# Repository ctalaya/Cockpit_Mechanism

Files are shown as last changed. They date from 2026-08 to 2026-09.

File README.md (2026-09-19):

# Cockpit_Mechanism

Modelos CAD y de simulación de un cockpit de simulación de conducción con geometría variable, capaz de reconfigurarse entre una posición de conducción tipo GT y una posición tipo Fórmula.

Este repositorio contiene los archivos que sustentan los resultados del Trabajo Fin de Máster **«Diseño y análisis cinemático de un cockpit de simulación de conducción con geometría variable»**, Máster Universitario en Ingeniería Industrial, Universidad Internacional de Valencia (VIU), curso 2025–2026.

**Autor:** Carlos Talaya Zamora
**Director:** José Andrés Alvarado Contreras

---

## Descripción del mecanismo

El mecanismo posee **dos grados de libertad** (criterio de Grübler-Kutzbach) gobernados por dos entradas de accionamiento coordinadas:

1. **Giro del asiento** sobre un eje fijo situado en el H-Point del conductor. Este giro arrastra, mediante un tren formado por un sector dentado, un piñón, un engranaje intermedio y una cremallera, el desplazamiento del módulo volante-pantalla sobre una guía inclinada.
2. **Actuador lineal** que gobierna el brazo estructural de la pedalera y, a través de una transmisión por cadena, el giro de la propia pedalera respecto a dicho brazo.

El H-Point permanece fijo durante toda la transformación, lo que constituye el criterio de diseño fundamental del mecanismo: el conductor no se desplaza en altura, sino que rota alrededor de su propio punto de cadera.

---

## Especificaciones de diseño

Recorridos requeridos para la transición GT → Fórmula, referidos al H-Point:

| Magnitud | Valor |
|---|---|
| Desplazamiento horizontal del volante | 237,39 mm |
| Desplazamiento vertical del volante | 70,64 mm |
| Desplazamiento longitudinal de la pedalera | 69,90 mm |
| Desplazamiento vertical de la pedalera | 553,65 mm |
| Giro del asiento sobre el H-Point | 32,5° |
| Giro absoluto de la pedalera | 21° |
| Desplazamiento del H-Point | 0 mm (punto fijo) |

## Parámetros de las transmisiones

**Tren de engranajes del módulo volante** (módulo m = 2 mm, ancho de cara 20 mm)

| Elemento | z | R primitivo |
|---|---|---|
| Sector dentado del asiento | 291 | 291,0 mm |
| Piñón | 20 | 20,0 mm |
| Engranaje intermedio | 30 | 30,0 mm |

Relación de transmisión i₁ = 14,555 · Recorrido de la cremallera 247,68 mm · Inclinación de la guía 16,58°

**Transmisión por cadena de la pedalera** (ISO 08B, paso 12,7 mm)

| Elemento | z | R primitivo |
|---|---|---|
| Piñón solidario al asiento | 27 | 54,70 mm |
| Piñón solidario a la pedalera | 15 | 30,55 mm |

Relación de transmisión i₂ = 1,7905 · Distancia entre ejes 387,0 mm · Longitud de cadena 82 eslabones (1.041,4 mm)

**Actuador lineal**

Longitud de referencia 150,0 mm · Carrera 17,86 mm · Giro relativo del brazo β = 14,55° · Velocidad de extensión 0,595 mm/s · Tiempo de operación 30 s

---

## Resultados de validación

Contraste entre los requisitos de diseño y los valores obtenidos en la simulación cinemática:

| Magnitud | Requisito | Simulación | Desviación |
|---|---|---|---|
| Desplazamiento horizontal del volante | 237,39 mm | 237,41 mm | 0,01 % |
| Desplazamiento vertical del volante | 70,64 mm | 70,64 mm | 0,00 % |
| Desplazamiento longitudinal de la pedalera | 69,90 mm | 70,09 mm | 0,27 % |
| Desplazamiento vertical de la pedalera | 553,65 mm | 551,46 mm | −0,40 % |
| Giro del asiento sobre el H-Point | 32,50° | 32,504° | 0,01 % |
| Giro absoluto de la pedalera | 21,00° | 21,04° | 0,19 % |

## Resultados dinámicos

Solicitaciones obtenidas en el análisis dinámico, por lateral del mecanismo:

| Magnitud | t = 0 s (GT) | t = 30 s (Fórmula) |
|---|---|---|
| Reacción en el apoyo del H-Point | 1.007,40 N | 1.007,40 N |
| Guía del módulo volante-pantalla | 305,90 N | 305,90 N |
| Revoluta brazo-pedalera | 249,48 N | 249,47 N |
| Revoluta asiento-brazo | 2.469,40 N | 3.511,60 N |
| Pasadores del actuador | 2.455,20 N | 3.667,40 N |
| Fuerza del actuador lineal | 2.455,70 N | 3.665,70 N |
| Par en el eje del H-Point | 141,93 N·m | 138,45 N·m |

El par alcanza su valor máximo de 151,71 N·m en t = 13,82 s. El mecanismo no presenta un instante crítico común a todas sus piezas: las solicitaciones de origen gravitatorio permanecen constantes, mientras que las asociadas al accionamiento del brazo crecen de forma monótona hasta la configuración Fórmula.

## Verificación resistente de las transmisiones

Acero S275JR, límite elástico 275 MPa.

| Elemento | Tensión | Factor de seguridad |
|---|---|---|
| Sector dentado (Lewis) | 5,69 MPa | 48,3 |
| Piñón (Lewis) | 8,56 MPa | 32,1 |
| Cremallera (Lewis) | 3,80 MPa | 72,5 |
| Cadena ISO 08B-1 (rotura) | T = 775 N | 23,2 |

Ambas transmisiones quedan gobernadas por las exigencias cinemáticas y no por las resistentes, lo que deja un margen de optimización económica pendiente de estudio específico.

---

## Estructura del repositorio

```
Cockpit_Mechanism/
├── Diseño 3D/
│   └── V2/              Modelo tridimensional del mecanismo (CATIA V5)
│       └── Planos/      Planos de conjunto y de detalle
├── Calculo/             Modelos de simulación de Ansys
├── Resultados/          Exportaciones de resultados en formato .xlsx
├── .gitattributes       Configuración de Git LFS
└── README.md
```

### Diseño 3D/V2

Modelo tridimensional completo del mecanismo elaborado en CATIA V5, en sus dos configuraciones extremas. Incluye las cinco piezas estructurales analizadas (eje del H-Point, asiento, brazo estructural de la pedalera, pedalera y soporte del volante-pantalla) y los componentes de las transmisiones.

### Calculo

Modelos de simulación:

- **Ansys Rigid Dynamics** — análisis cinemático y dinámico del mecanismo completo a lo largo de los 30 s de la transformación.
- **Ansys Mechanical** — análisis estructural estático de cada una de las cinco piezas.

### Resultados

Exportaciones de resultados en formato `.xlsx`, con 603 pasos de tiempo cada una:

- `Cinematica.xlsx` — giros, velocidades y aceleraciones angulares de los tres ejes principales.
- `Fuerzas internas.xlsx` — fuerzas transmitidas en las seis uniones del mecanismo.
- `Fuerzas actuador y par.xlsx` — fuerza requerida en el actuador lineal y par en el eje del H-Point.

---

## Nota sobre las Constraint Equations

Los engranajes y la transmisión por cadena se han modelado sin dentado, representándolos por sus cilindros primitivos. Las relaciones de transmisión se imponen mediante **Constraint Equations** sobre los grados de libertad de los joints, procedimiento documentado por Ansys para vincular velocidades angulares sin necesidad de modelar el contacto entre dientes.

Esta simplificación es deliberada: el objetivo del análisis es verificar la cinemática de la transformación, no evaluar tensiones de contacto en el dentado. Como consecuencia, el modelo no proporciona fuerzas de engrane ni presiones de contacto, y la transmisión es ideal, sin holguras ni pérdidas por rozamiento.

Debe señalarse que, al no derivarse estas ecuaciones de la geometría sino imponerse explícitamente, el programa reproduce la relación indicada sea o no la correcta. La verificación independiente de las magnitudes de salida frente a los requisitos de partida resulta, por tanto, imprescindible.

---

## Requisitos de software

| Software | Versión empleada |
|---|---|
| CATIA V5 | — |
| Ansys Mechanical / Rigid Dynamics | 2025 R1 |
| Git LFS | Necesario para clonar el repositorio |

## Clonado del repositorio

Los archivos de modelado y simulación se almacenan mediante **Git Large File Storage**. Es necesario instalar Git LFS antes de clonar:

```bash
git lfs install
git clone https://github.com/ctalaya/Cockpit_Mechanism.git
```

Sin Git LFS, el clonado descargará únicamente los punteros a los archivos, no su contenido.

---

## Licencia y uso

Este repositorio se publica con fines académicos, como material de soporte y verificación del Trabajo Fin de Máster referido. Cualquier uso posterior de su contenido debe citar la fuente:

> Talaya Zamora, C. (2026). *Cockpit_Mechanism: modelos CAD y de simulación de un cockpit reconfigurable* [Repositorio de software]. GitHub. https://github.com/ctalaya/Cockpit_Mechanism

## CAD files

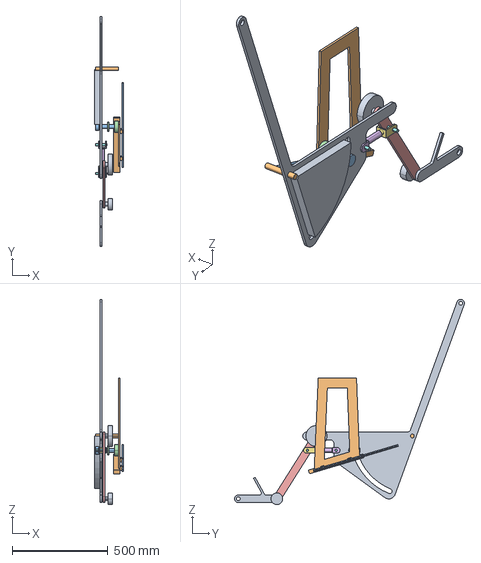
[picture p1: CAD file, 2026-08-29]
Calculo/Modelo/TFM_V2.stp
153.0 x 1199.4 x 1070.5 mm

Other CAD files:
Diseño 3D/V2/Actuador/Actuador.CATProduct
Diseño 3D/V2/Actuador/Base actuador.CATPart
Diseño 3D/V2/Actuador/Vastago actuador.CATPart
Diseño 3D/V2/Asiento V2.CATPart
Diseño 3D/V2/Brazo Estructural de la Pedalera V2.CATPart
Diseño 3D/V2/Brazo exterior volante V2.CATPart
Diseño 3D/V2/Brazo interior volante V2.CATPart
Diseño 3D/V2/Eje V2.CATPart
Diseño 3D/V2/Eje2.CATPart
Diseño 3D/V2/Engranaje Grande.CATPart
Diseño 3D/V2/Engranaje Peque.CATPart
Diseño 3D/V2/Guia V2.CATPart
Diseño 3D/V2/Guia Volante.CATPart
Diseño 3D/V2/Mecanismo Cockpit V2.CATProduct
Diseño 3D/V2/Pedalera V2.CATPart
Diseño 3D/V2/Soporte Eje.CATPart
Diseño 3D/V2/Volante.CATPart

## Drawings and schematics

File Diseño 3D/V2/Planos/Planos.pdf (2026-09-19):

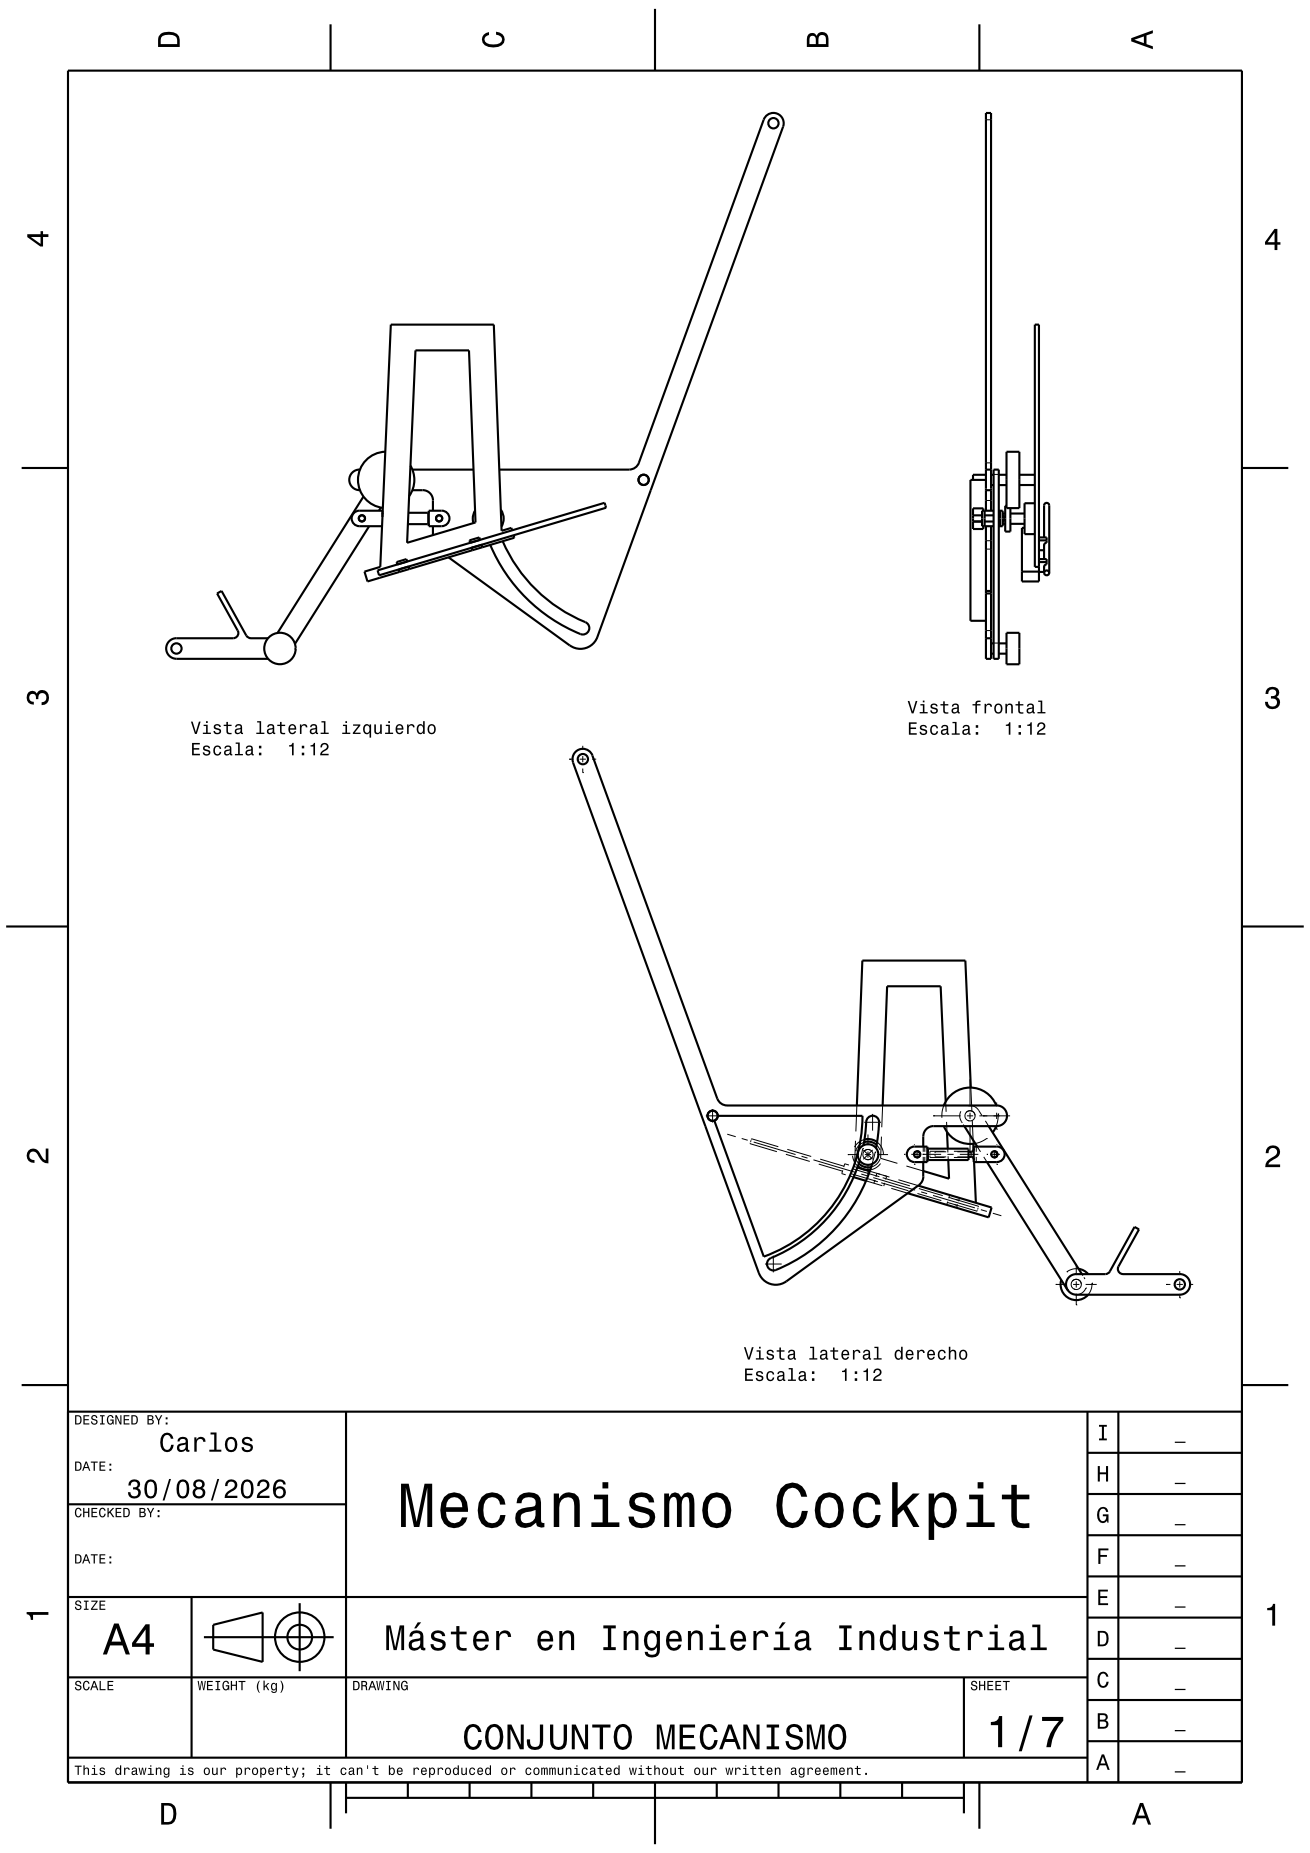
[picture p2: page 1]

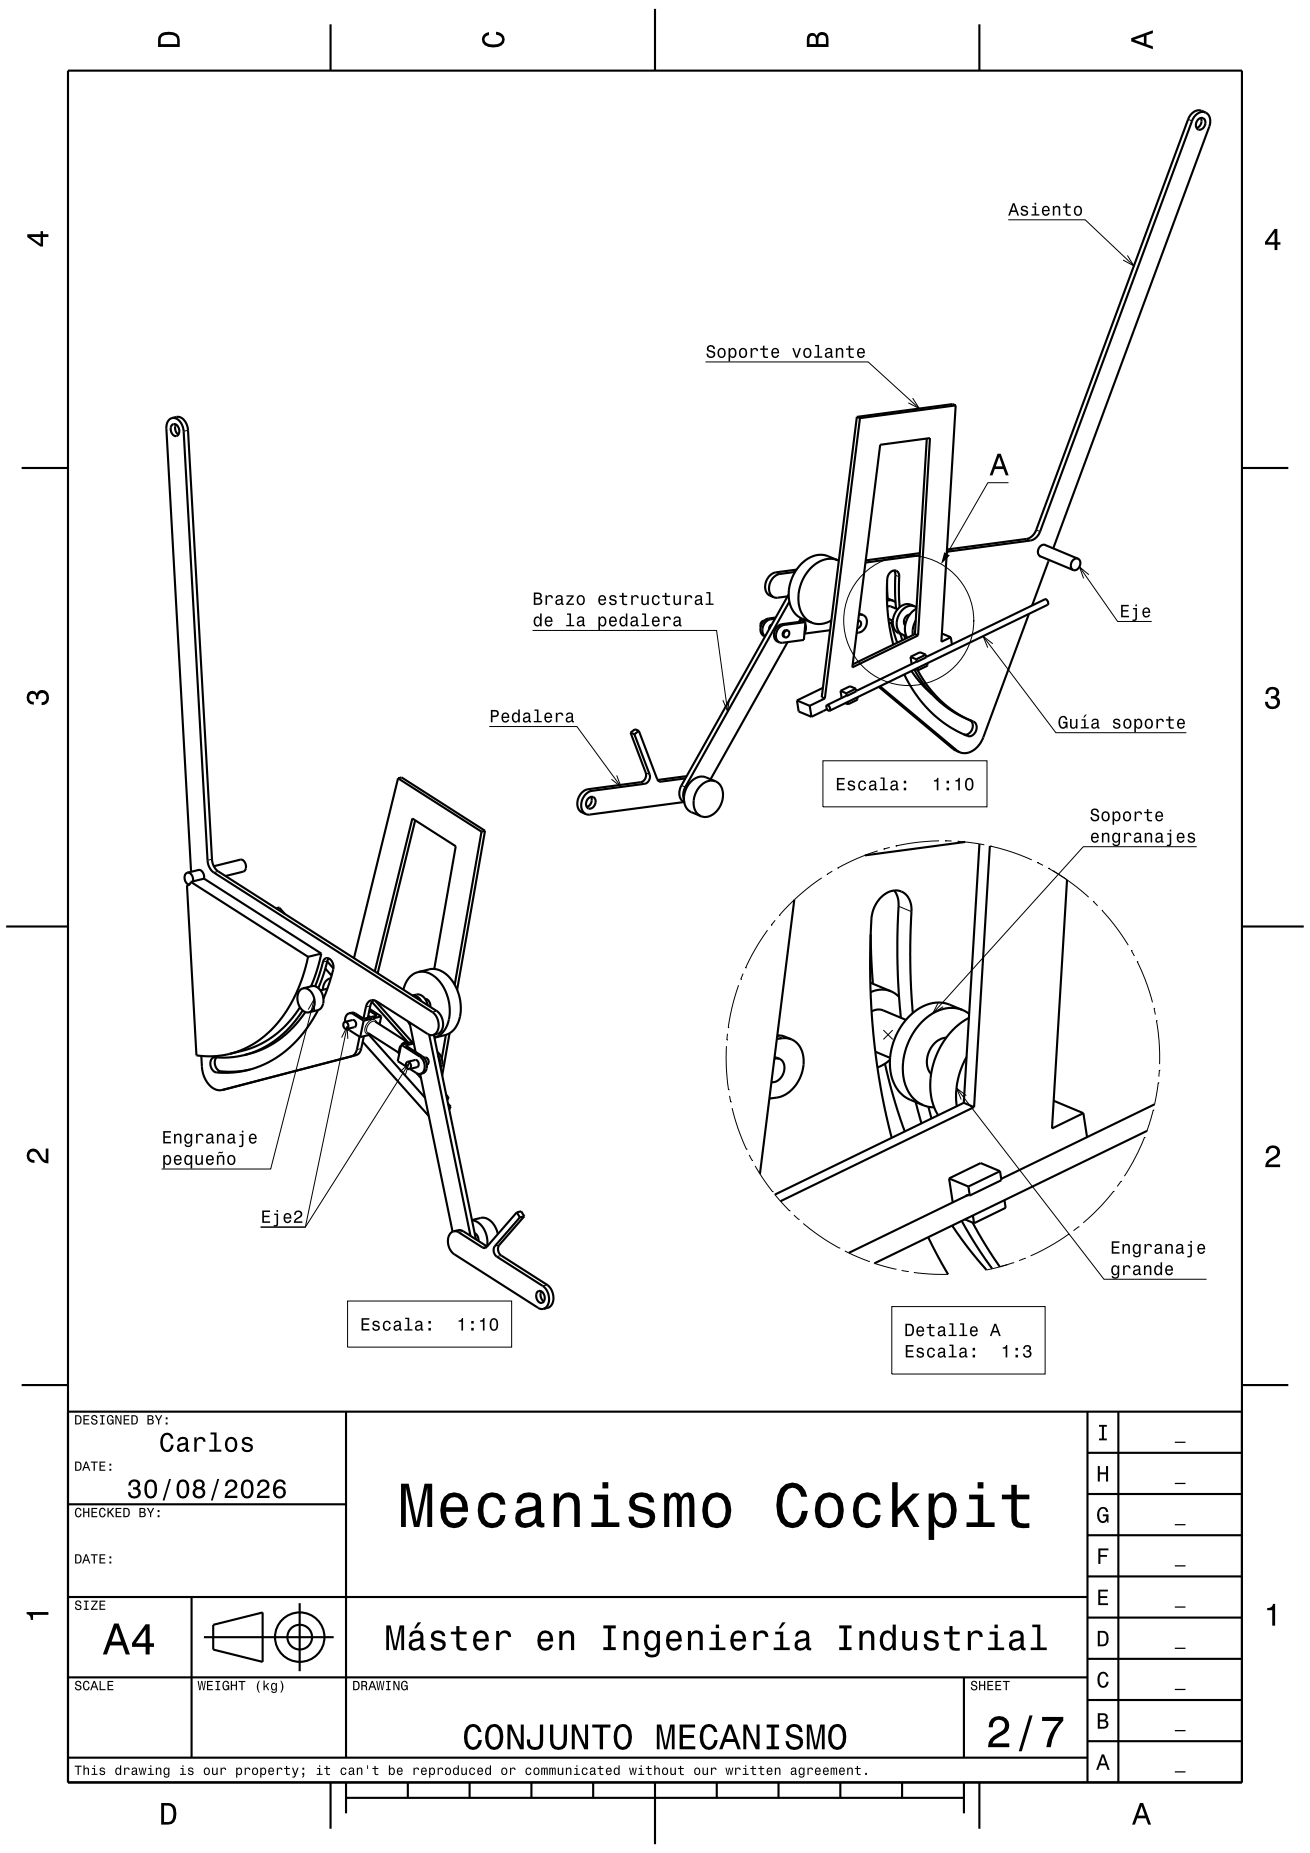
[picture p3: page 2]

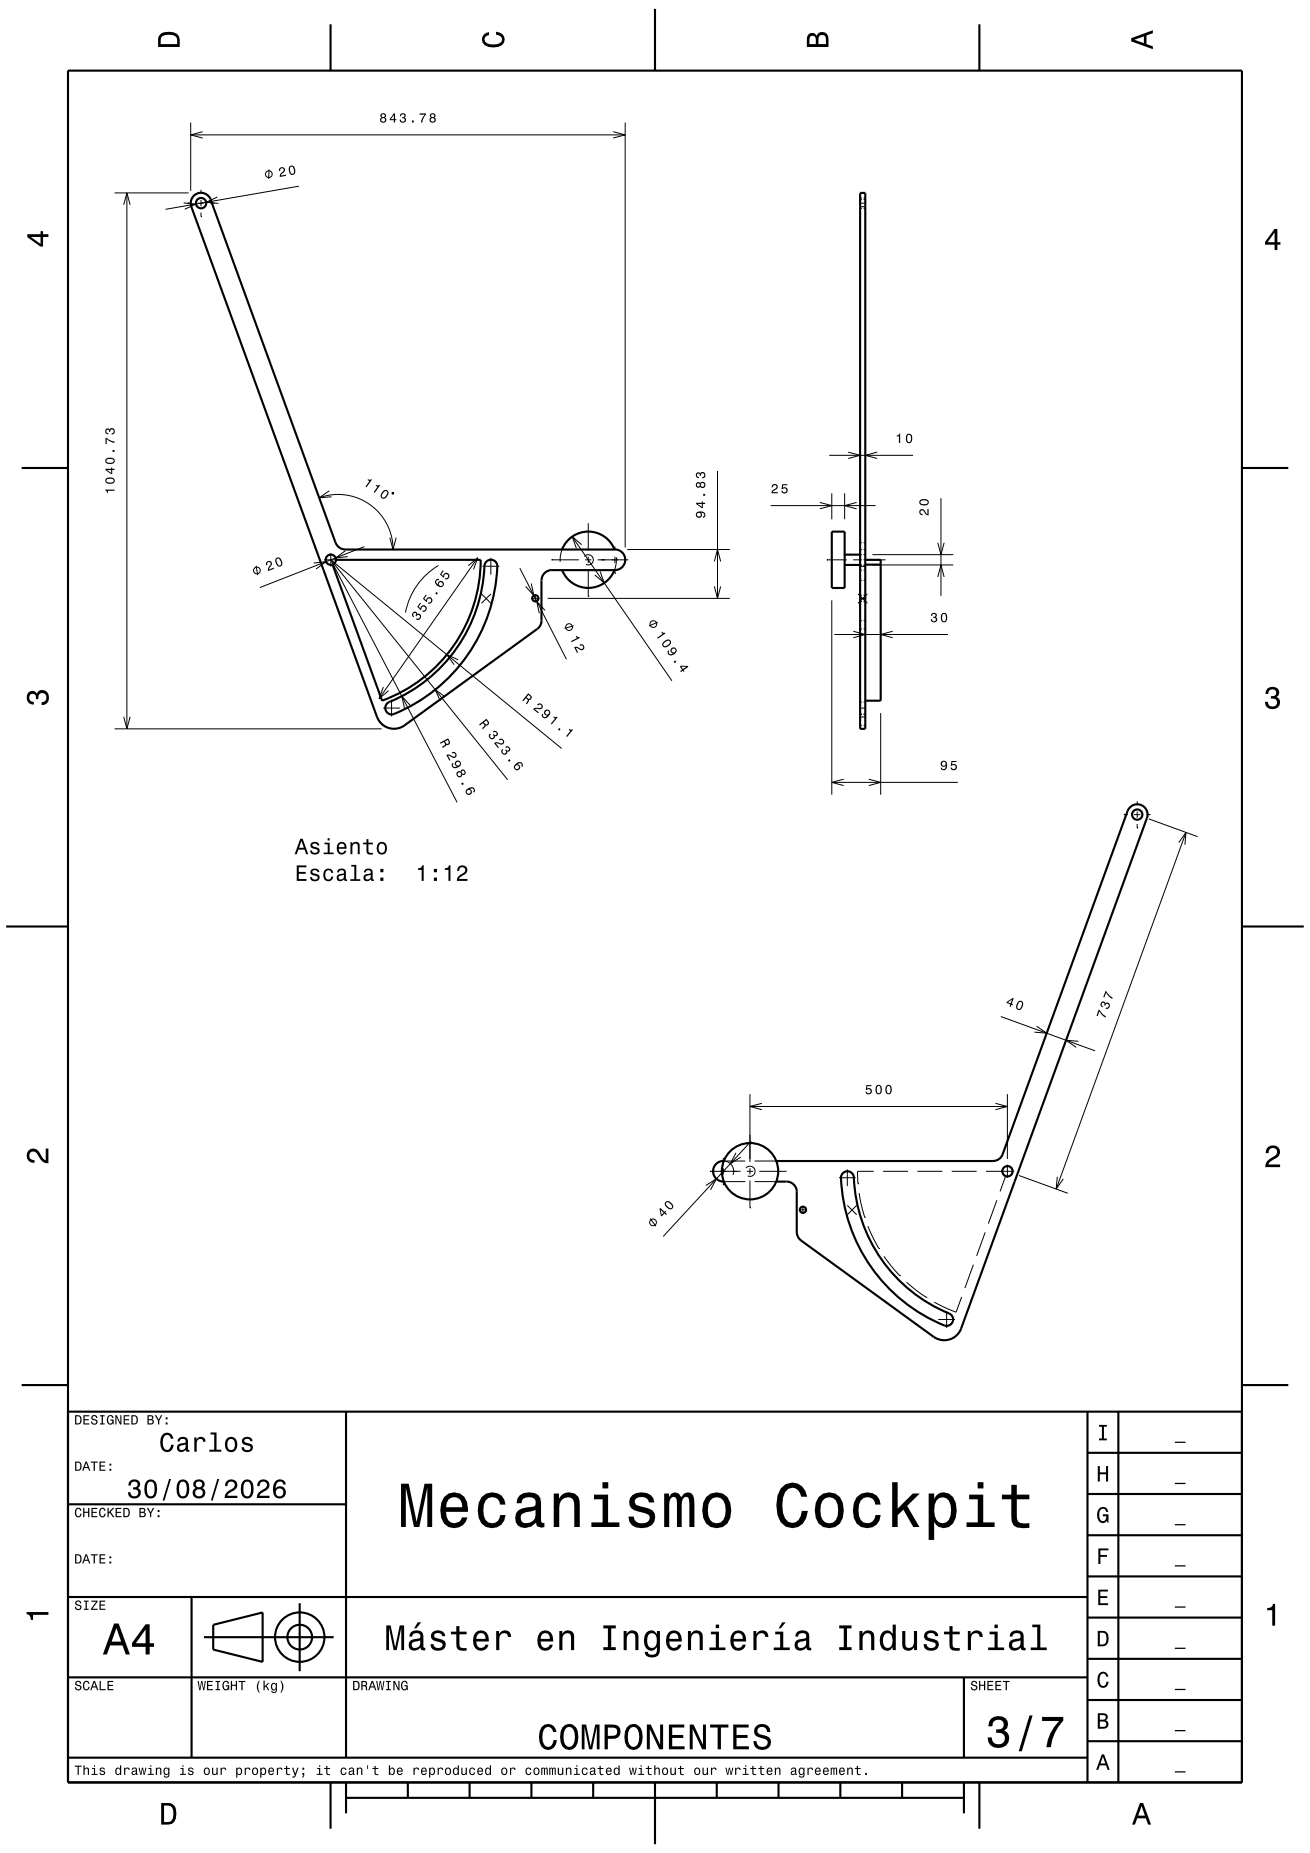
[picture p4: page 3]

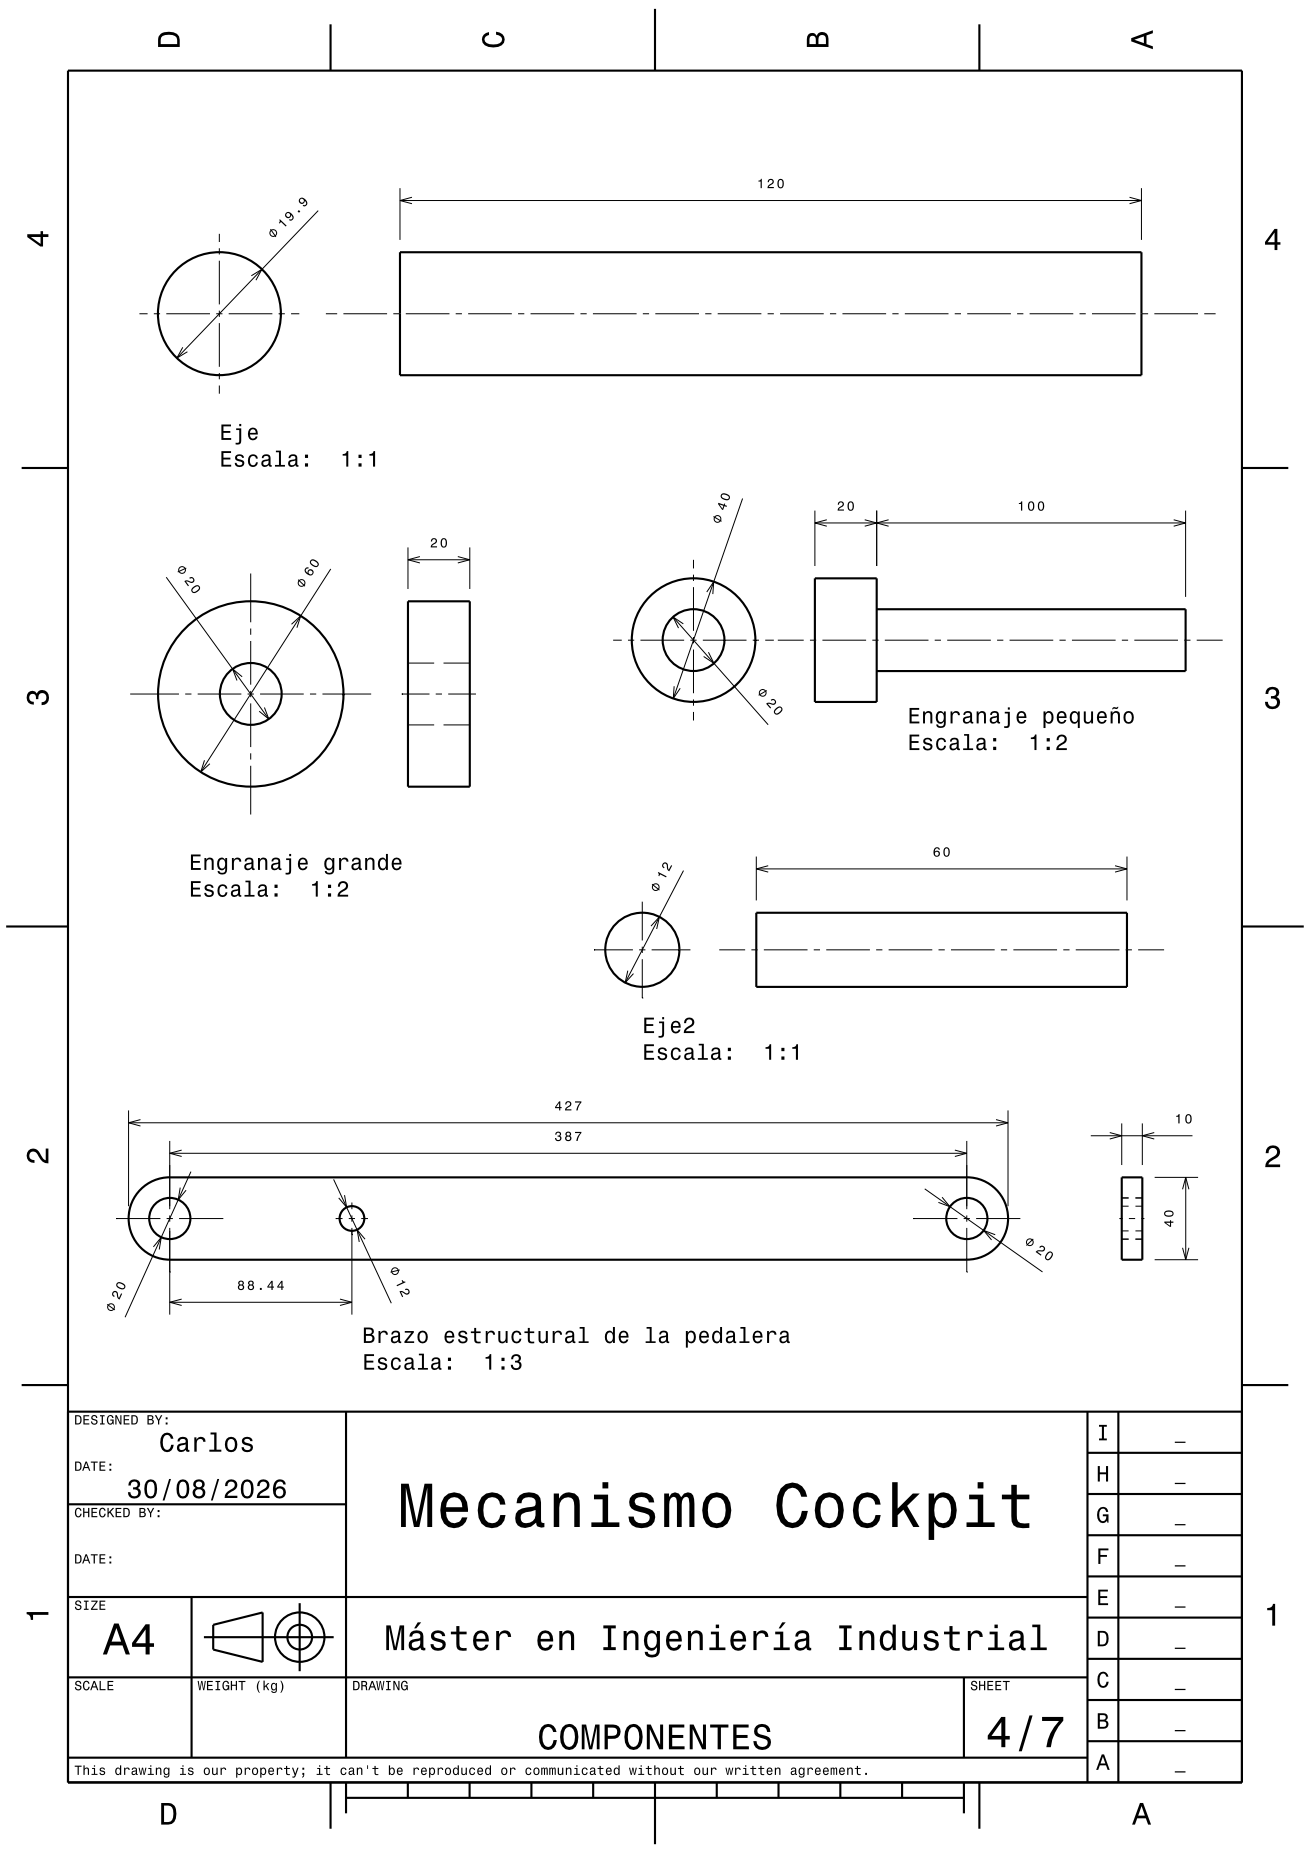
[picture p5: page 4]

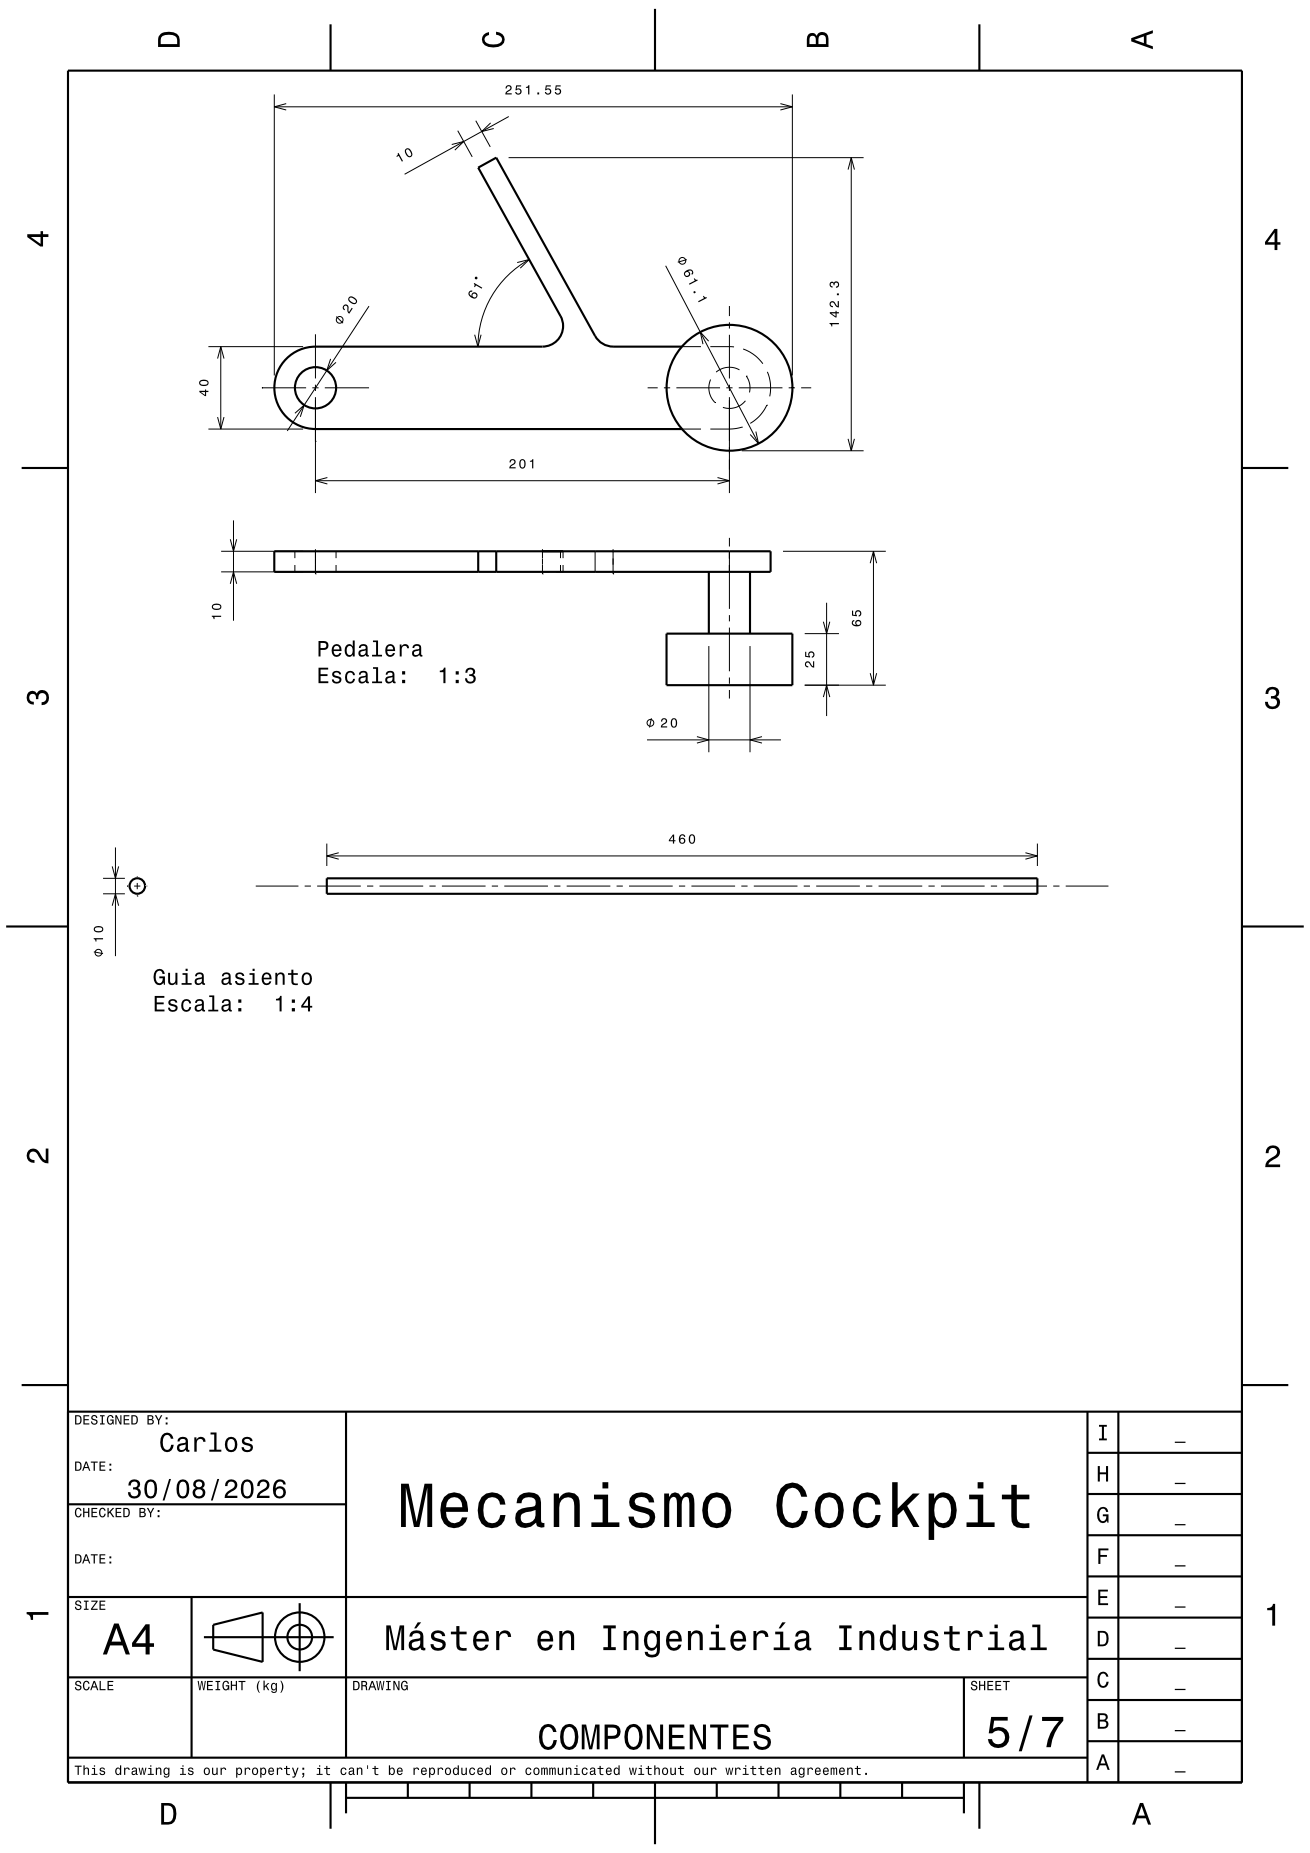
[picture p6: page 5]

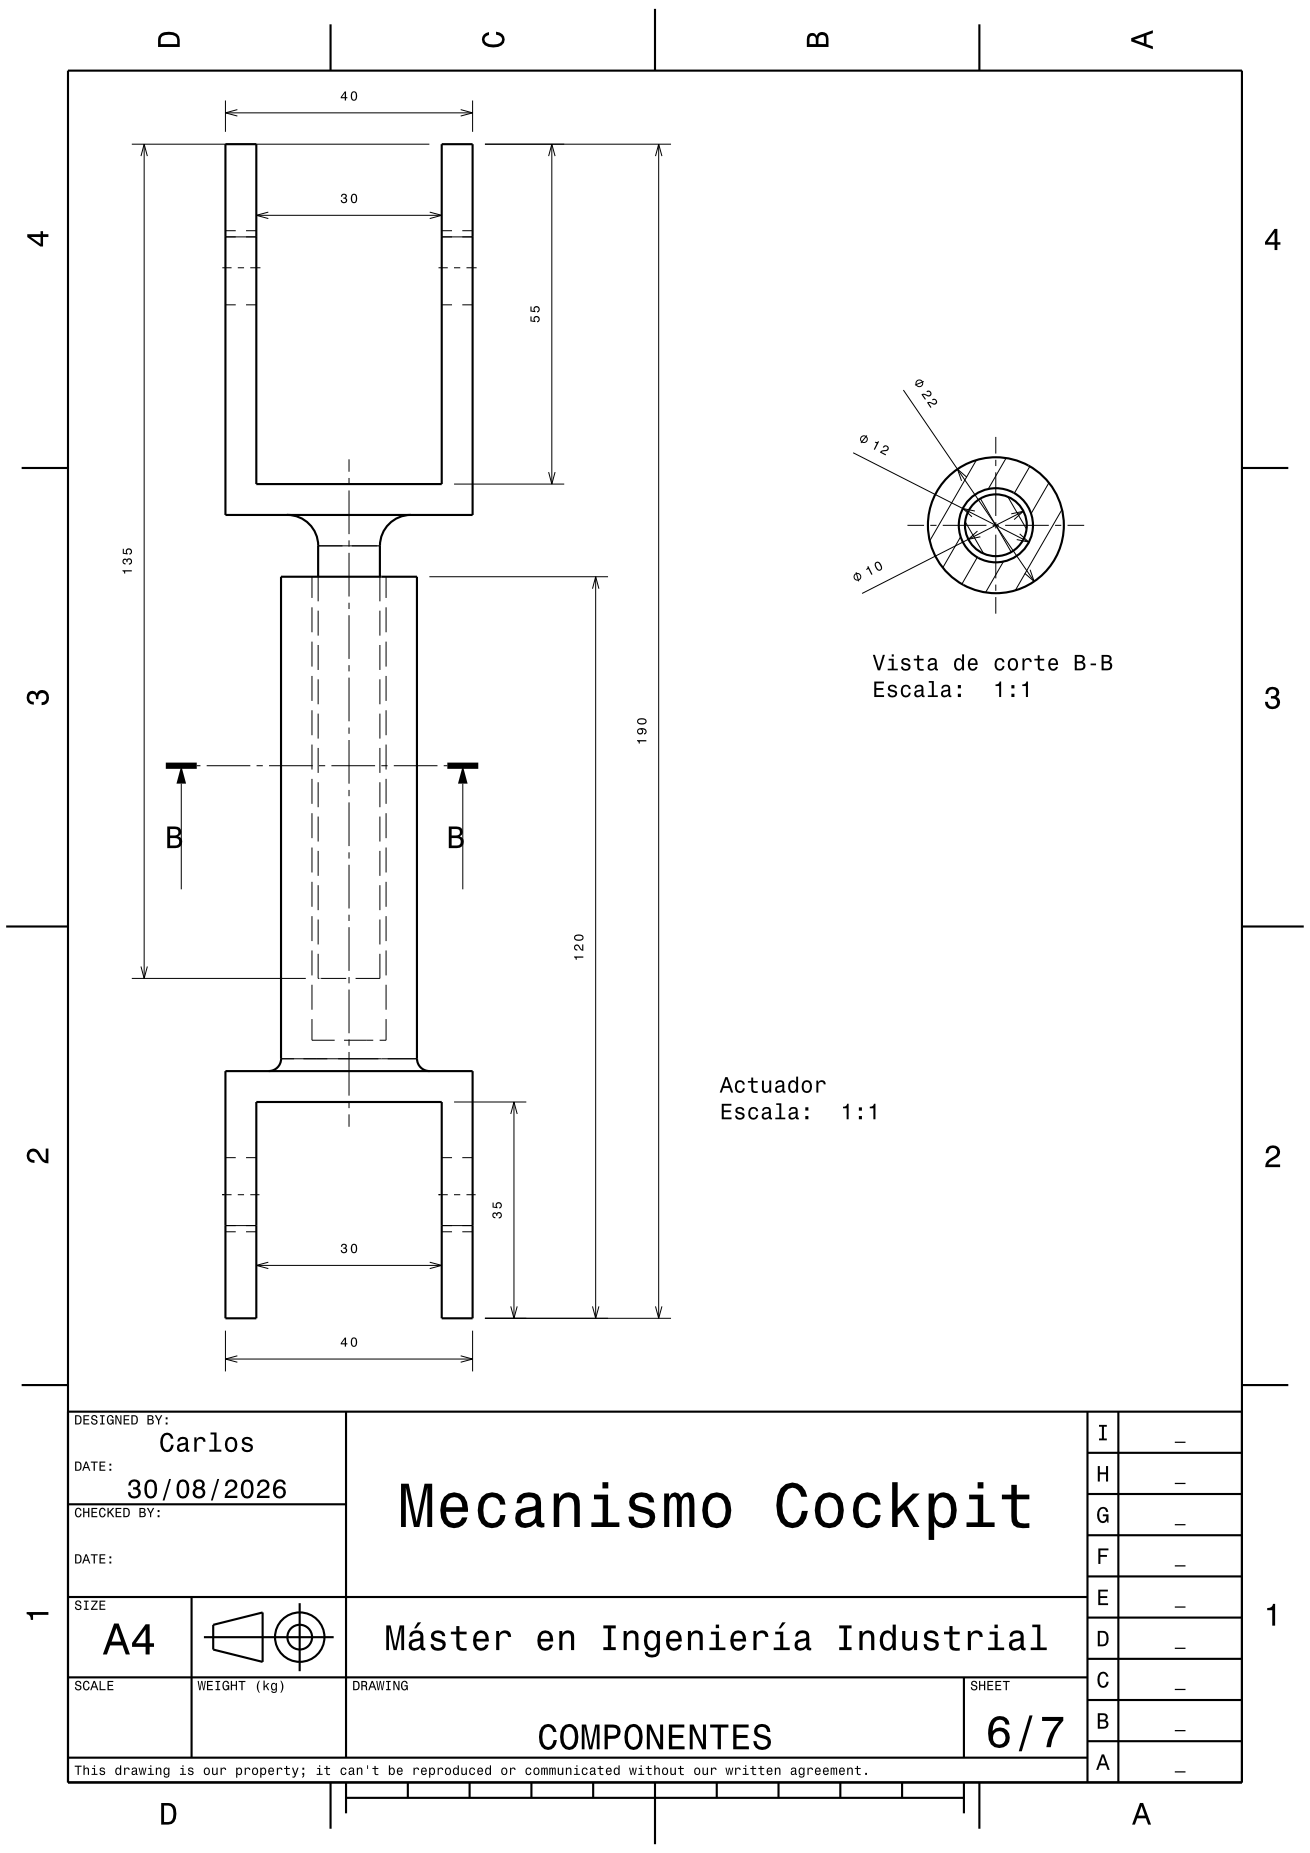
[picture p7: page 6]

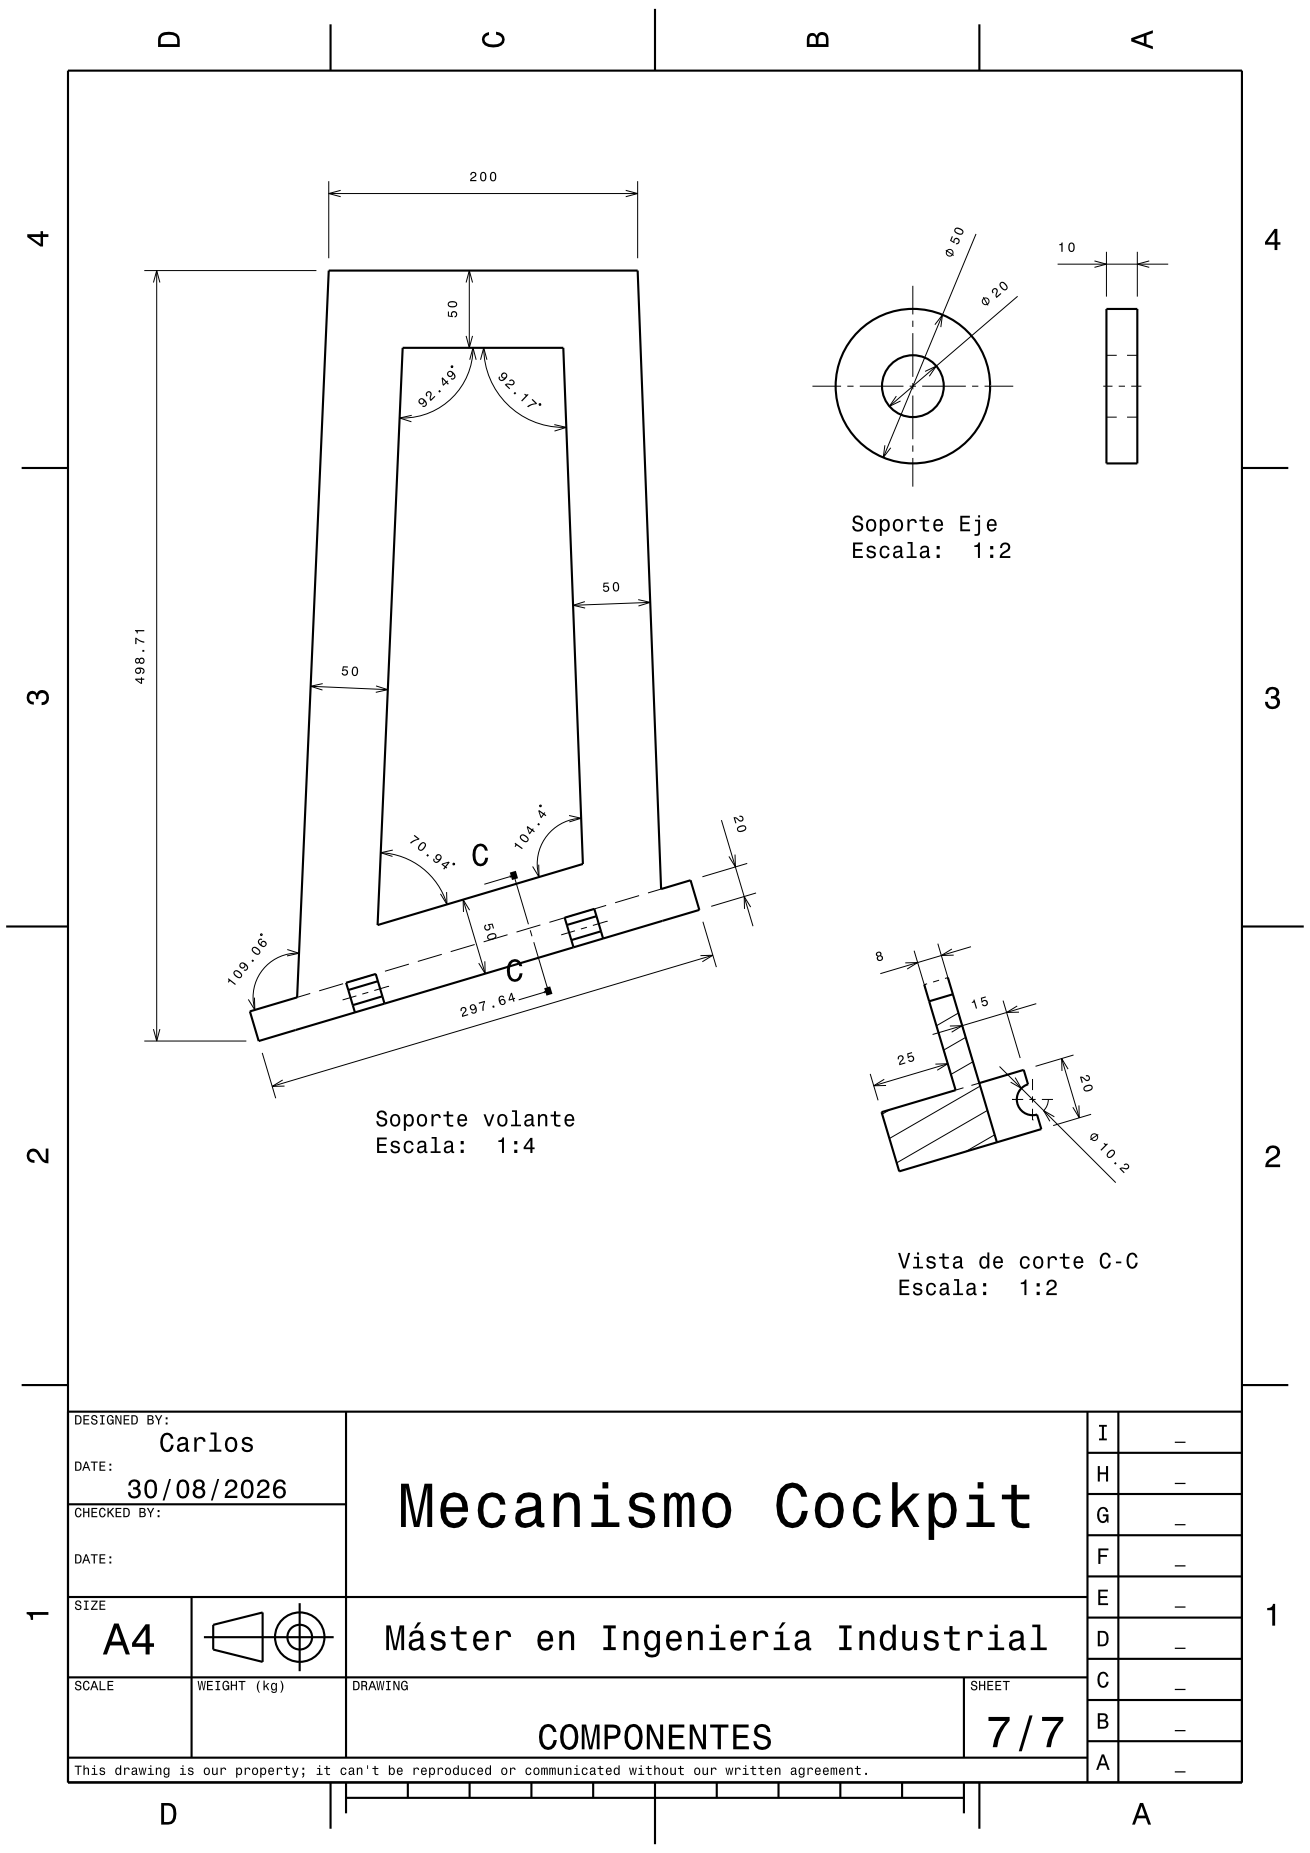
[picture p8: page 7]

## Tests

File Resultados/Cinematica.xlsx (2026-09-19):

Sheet: Eje asiento
Time (s) | Rotation Eje Asiento (Relative Rotation Z) | Time (s) | Angular Velocity Eje Asiento (Relative Angular Velocity Z) | Time (s) | AngularAcceleration Eje Asiento (Relative Angular Acceleration Z)
0.00000 | 0.00000 | 0.00000 | -0.01891 | 0.00000 | -1.7058e-20
0.01000 | -0.01083 | 0.01000 | -0.01891 | 0.01000 | 1.658e-19
0.03000 | -0.03250 | 0.03000 | -0.01891 | 0.03000 | 5.4583e-20
0.07000 | -0.07584 | 0.07000 | -0.01891 | 0.07000 | -2.7358e-19
0.12000 | -0.13002 | 0.12000 | -0.01891 | 0.12000 | -1.3575e-19
0.17000 | -0.18419 | 0.17000 | -0.01891 | 0.17000 | 2.9263e-19
0.22000 | -0.23836 | 0.22000 | -0.01891 | 0.22000 | 4.0242e-20
0.27000 | -0.29254 | 0.27000 | -0.01891 | 0.27000 | -3.6147e-20
0.32000 | -0.34671 | 0.32000 | -0.01891 | 0.32000 | 2.5232e-19
0.37000 | -0.40088 | 0.37000 | -0.01891 | 0.37000 | -2.0116e-19
0.42000 | -0.45505 | 0.42000 | -0.01891 | 0.42000 | -2.7751e-19
0.47000 | -0.50923 | 0.47000 | -0.01891 | 0.47000 | -4.4452e-19
0.52000 | -0.56340 | 0.52000 | -0.01891 | 0.52000 | -2.386e-20
0.57000 | -0.61757 | 0.57000 | -0.01891 | 0.57000 | -3.4083e-21
0.62000 | -0.67175 | 0.62000 | -0.01891 | 0.62000 | 6.1344e-20
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

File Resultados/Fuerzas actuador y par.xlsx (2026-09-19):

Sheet: Hoja1
Time (s) | All - Total Moment - Joint Probe - Revolute - Eje|PartBody To Asiento|PartBody - End Time Total Moment X | All - Total Moment - Joint Probe - Revolute - Eje|PartBody To Asiento|PartBody - End Time Total Moment Y | All - Total Moment - Joint Probe - Revolute - Eje|PartBody To Asiento|PartBody - End Time Total Moment Z | All - Total Moment - Joint Probe - Revolute - Eje|PartBody To Asiento|PartBody - End Time Total Moment Total
0 | 0.96237 | 63430 | -126950 | 141920
0.01 | 0.96266 | 63430 | -126970 | 141930
0.03 | 0.96322 | 63430 | -127000 | 141960
0.07 | 0.96434 | 63430 | -127060 | 142010
0.12 | 0.96574 | 63430 | -127130 | 142080
0.17 | 0.96714 | 63430 | -127200 | 142140
0.22 | 0.96854 | 63430 | -127280 | 142210
0.27 | 0.96994 | 63430 | -127350 | 142270
0.32 | 0.97133 | 63430 | -127420 | 142340
0.37 | 0.97273 | 63430 | -127500 | 142400
0.42 | 0.97412 | 63430 | -127570 | 142470
0.47 | 0.97552 | 63430 | -127640 | 142530
0.52 | 0.97691 | 63430 | -127710 | 142600
0.57 | 0.9783 | 63430 | -127780 | 142660
0.62 | 0.97969 | 63430 | -127850 | 142720
0.67 | 0.98108 | 63430 | -127920 | 142790
0.72 | 0.98247 | 63430 | -128000 | 142850
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

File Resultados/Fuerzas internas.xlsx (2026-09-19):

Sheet: Hoja1
Time (s) | All - Total Force - Joint Probe - Fixed - Ground To Eje|PartBody - End Time Total Force X (N) | All - Total Force - Joint Probe - Fixed - Ground To Eje|PartBody - End Time Total Force Y (N) | All - Total Force - Joint Probe - Fixed - Ground To Eje|PartBody - End Time Total Force Z (N) | All - Total Force - Joint Probe - Fixed - Ground To Eje|PartBody - End Time Total Force Total (N)
0 | -1007.4 | 0.0095314 | 2.237e-13 | 1007.4
0.01 | -1007.4 | 0.0095332 | 2.237e-13 | 1007.4
0.03 | -1007.4 | 0.0095367 | 2.237e-13 | 1007.4
0.07 | -1007.4 | 0.0095437 | 2.237e-13 | 1007.4
0.12 | -1007.4 | 0.0095525 | 2.237e-13 | 1007.4
0.17 | -1007.4 | 0.0095613 | 2.237e-13 | 1007.4
0.22 | -1007.4 | 0.0095701 | 2.237e-13 | 1007.4
0.27 | -1007.4 | 0.0095788 | 2.237e-13 | 1007.4
0.32 | -1007.4 | 0.0095876 | 2.237e-13 | 1007.4
0.37 | -1007.4 | 0.0095963 | 2.237e-13 | 1007.4
0.42 | -1007.4 | 0.0096051 | 2.237e-13 | 1007.4
0.47 | -1007.4 | 0.0096138 | 2.237e-13 | 1007.4
0.52 | -1007.4 | 0.0096225 | 2.237e-13 | 1007.4
0.57 | -1007.4 | 0.0096312 | 2.237e-13 | 1007.4
0.62 | -1007.4 | 0.0096399 | 2.237e-13 | 1007.4
0.67 | -1007.4 | 0.0096486 | 2.237e-13 | 1007.4
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

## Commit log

2026-08-29 Configurar Git LFS para archivos CAD y ANSYS
2026-08-29 Añadir modelo 3D y análisis ANSYS
    [Actuador.CATProduct, Asiento V2.CATPart, Base actuador.CATPart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]
2026-09-19 Actualizacion de resultados tras correccion de la ecuacion de restriccion, planos y README
    [Cinematica.xlsx, Eje 3.CATPart, Eje principal Yugo grande.CATPart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]
2026-09-19 Actualizacion del README con la estructura real del repositorio
